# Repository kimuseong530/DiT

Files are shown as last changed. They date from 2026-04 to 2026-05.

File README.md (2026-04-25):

# DiT — Digital Twin Truck

> 손 제스처로 조종하는 소형 트럭 + Unity 디지털 트윈 실시간 동기화 시스템

---

## 프로젝트 개요
장갑에 내장된 IMU 센서로 손의 움직임을 인식하고,
Wi-Fi(MQTT) 통신을 통해 3D 프린팅 기반 소형 트럭을 제어합니다.
트럭의 실시간 위치·자세 데이터는 Unity 가상환경에 동기화되어
디지털 트윈으로 시각화됩니다.

---

## 시스템 구성

[ 장갑 (ESP32 + MPU-6050) ]
        ↓ MQTT (glove/left, glove/right)
[ Raspberry Pi — Mosquitto 브로커 ]
        ↓ MQTT (truck/cmd, truck/sensor)
[ 트럭 ESP32 — TB6612FNG — DC모터 ]
        ↓ MQTT (truck/sensor)
[ Unity 디지털 트윈 ]

---

## 제스처 동작 매핑

| 동작 | 기능 | 인식 방법 |
|---|---|---|
| 팔을 앞으로 밀기 | 전진 | Pitch + |
| 팔을 뒤로 당기기 | 후진 | Pitch − |
| 왼쪽으로 기울임 | 좌회전 | Roll − |
| 오른쪽으로 기울임 | 우회전 | Roll + |
| 양손 위로 | 정지 | Z축 기준 |

---

## MQTT 토픽 구조

| 토픽 | 발행자 | 구독자 | 내용 |
|---|---|---|---|
| `glove/left` | 왼손 ESP32 | 트럭, Unity | pitch/roll/yaw |
| `glove/right` | 오른손 ESP32 | 트럭, Unity | pitch/roll/yaw |
| `truck/cmd` | 트럭 ESP32 | Unity | 모터 명령값 |
| `truck/sensor` | 트럭 ESP32 | Unity | 인코더 피드백 |

---

## 하드웨어 구성
- ESP32 DevKitC WROOM-32D × 3
- MPU-6050 (GY-521) × 2
- TB6612FNG 모터드라이버 × 1
- 인코더 내장 DC모터 (6V 52RPM) × 2
- Raspberry Pi 4 Model B (MQTT 브로커)

---

## 실행 방법

### 1. Raspberry Pi — MQTT 브로커
```bash
cd raspberry_pi
bash setup.sh
```

### 2. ESP32 — 장갑 / 트럭
- `secrets.h`에 Wi-Fi SSID/PW 입력
- Arduino IDE에서 각 `.ino` 업로드

### 3. Unity
- `unity/` 폴더를 Unity Hub에서 열기
- MQTT 브로커 IP 설정 후 실행

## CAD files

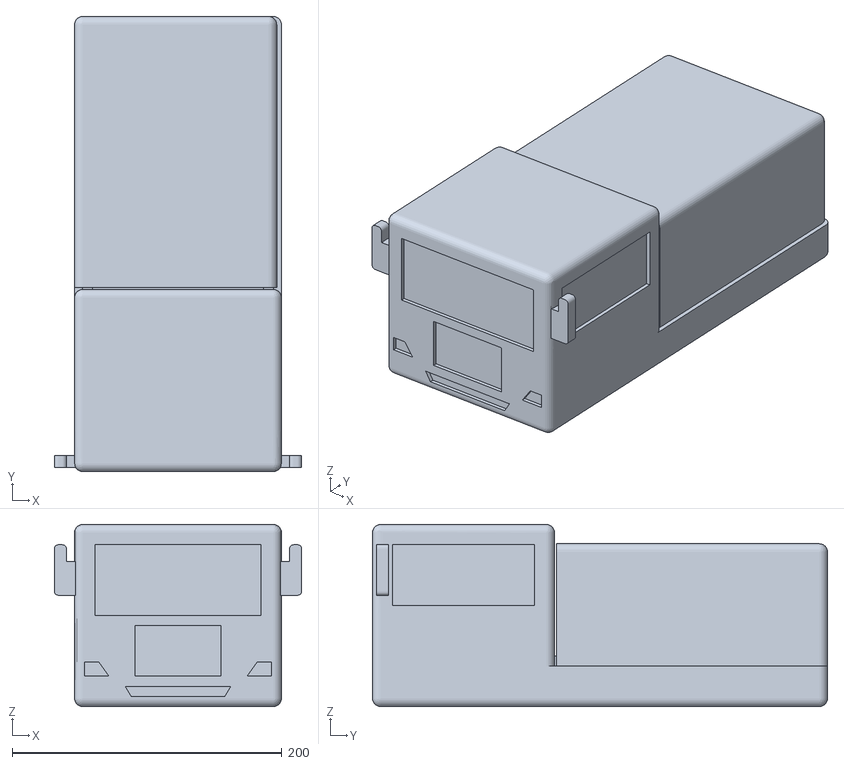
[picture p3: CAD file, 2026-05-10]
3d_model/Truck.stl
183.5 x 337.5 x 135.0

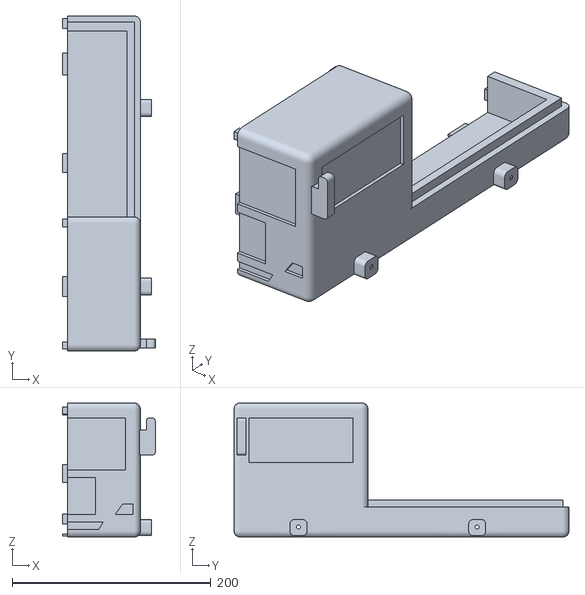
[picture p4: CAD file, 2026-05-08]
3d_model/truck_half(test).stl
93.2 x 337.5 x 135.0

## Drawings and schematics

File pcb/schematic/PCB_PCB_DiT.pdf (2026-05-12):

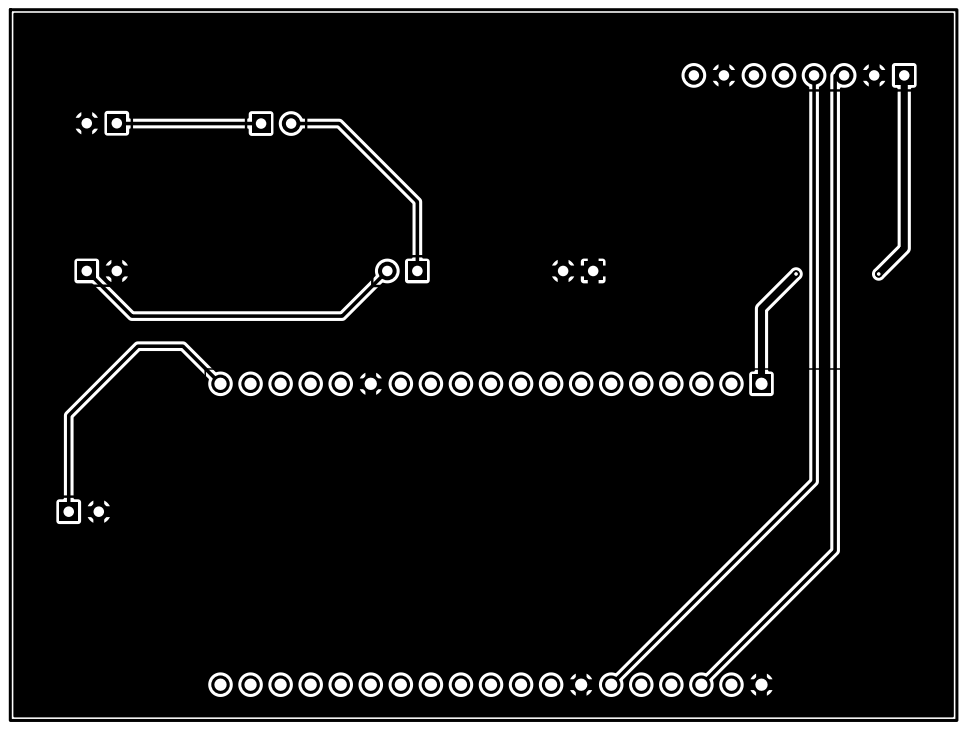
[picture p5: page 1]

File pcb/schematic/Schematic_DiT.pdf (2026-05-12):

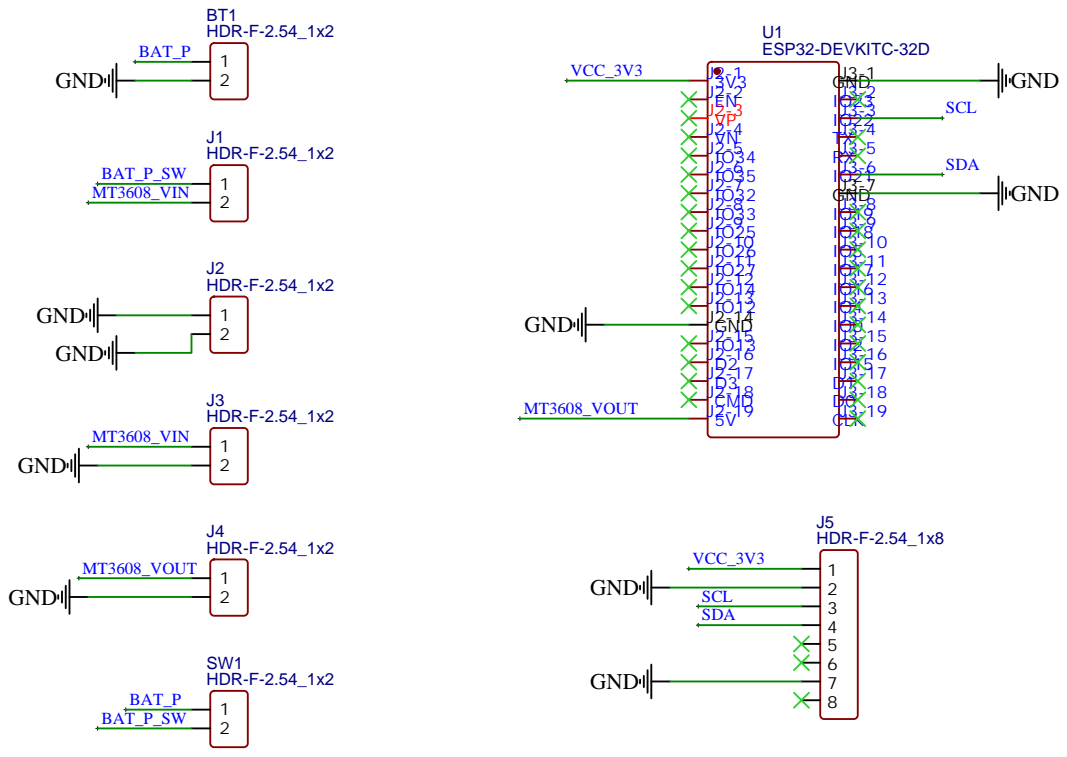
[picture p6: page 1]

Drawn By: Kim USeong

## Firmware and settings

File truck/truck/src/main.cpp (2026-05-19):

// #include <Arduino.h>
// #include <WiFi.h>
// #include <PubSubClient.h>
// #include <ArduinoJson.h>

// // ⚠️ Wi-Fi / MQTT 설정
// const char* WIFI_SSID     = "여기에_SSID";
// const char* WIFI_PASSWORD = "여기에_PW";
// const char* MQTT_BROKER   = "라즈베리파이_IP";
// const int   MQTT_PORT     = 1883;

// // ===== TB6612FNG 핀 정의 =====
// #define AIN1 25
// #define AIN2 26
// #define PWMA 27
// #define BIN1 14
// #define BIN2 23   // ✅ 12 → 23 변경 (부팅 문제 핀 회피)
// #define PWMB 13

// // ===== 인코더 핀 정의 =====
// #define ENC_L_A 18
// #define ENC_L_B 19
// #define ENC_R_A 34
// #define ENC_R_B 35

// // ===== LEDC PWM 설정 =====
// // ✅ ESP32는 analogWrite 없음 → ledcWrite 사용
// #define CH_L      0
// #define CH_R      1
// #define PWM_FREQ  5000
// #define PWM_BIT   8     // 0~255

// // ===== 인코더 스펙 =====
// #define PPR          11
// #define GEAR_RATIO   298
// #define WHEEL_RADIUS 0.033   // 66mm → 반지름 33mm
// #define WHEEL_BASE   0.15     // 바퀴 간격 (실측 후 수정!)

// // ===== 제스처 임계값 =====
// #define PITCH_FWD    15.0
// #define PITCH_BWD   -15.0
// #define ROLL_RIGHT   15.0
// #define ROLL_LEFT   -15.0
// #define STOP_AZ      0.3
// #define MOTOR_SPEED  150

// // ===== 인코더 변수 =====
// volatile long encL_count = 0;
// volatile long encR_count = 0;

// float distL_total = 0;
// float distR_total = 0;
// float heading     = 0;

// const float DIST_PER_PULSE = (2.0 * PI * WHEEL_RADIUS) / (PPR * GEAR_RATIO);

// // ===== 장갑 데이터 =====
// float left_pitch = 0, left_roll = 0, left_az = 1;
// float right_pitch = 0, right_roll = 0, right_az = 1;

// WiFiClient espClient;
// PubSubClient mqtt(espClient);

// unsigned long lastSensorPublish = 0;
// #define SENSOR_INTERVAL 100

// // ===== 인터럽트 핸들러 =====
// void IRAM_ATTR encL_ISR() {
//   if (digitalRead(ENC_L_B) == HIGH) encL_count++;
//   else encL_count--;
// }

// void IRAM_ATTR encR_ISR() {
//   if (digitalRead(ENC_R_B) == HIGH) encR_count++;
//   else encR_count--;
// }

// // ===== 모터 제어 함수 =====
// // ✅ analogWrite → ledcWrite 전체 교체
// void motorStop() {
//   digitalWrite(AIN1, LOW); digitalWrite(AIN2, LOW); ledcWrite(CH_L, 0);
//   digitalWrite(BIN1, LOW); digitalWrite(BIN2, LOW); ledcWrite(CH_R, 0);
//   Serial.println("🛑 정지");
// }

// void motorForward(int speed) {
//   digitalWrite(AIN1, HIGH); digitalWrite(AIN2, LOW); ledcWrite(CH_L, speed);
//   digitalWrite(BIN1, HIGH); digitalWrite(BIN2, LOW); ledcWrite(CH_R, speed);
//   Serial.println("⬆️ 전진");
// }

// void motorBackward(int speed) {
//   digitalWrite(AIN1, LOW); digitalWrite(AIN2, HIGH); ledcWrite(CH_L, speed);
//   digitalWrite(BIN1, LOW); digitalWrite(BIN2, HIGH); ledcWrite(CH_R, speed);
//   Serial.println("⬇️ 후진");
// }

// void motorLeft(int speed) {
//   digitalWrite(AIN1, LOW); digitalWrite(AIN2, HIGH); ledcWrite(CH_L, speed);
//   digitalWrite(BIN1, HIGH); digitalWrite(BIN2, LOW); ledcWrite(CH_R, speed);
//   Serial.println("⬅️ 좌회전");
// }

// void motorRight(int speed) {
//   digitalWrite(AIN1, HIGH); digitalWrite(AIN2, LOW); ledcWrite(CH_L, speed);
//   digitalWrite(BIN1, LOW); digitalWrite(BIN2, HIGH); ledcWrite(CH_R, speed);
//   Serial.println("➡️ 우회전");
// }

// // ===== 인코더 → 거리/방향 계산 =====
// void updateOdometry() {
//   long countL = encL_count; encL_count = 0;
//   long countR = encR_count; encR_count = 0;

//   float dL = countL * DIST_PER_PULSE;
//   float dR = countR * DIST_PER_PULSE;

//   distL_total += abs(dL);
//   distR_total += abs(dR);

//   float dTheta = (dR - dL) / WHEEL_BASE;
//   heading += dTheta * (180.0 / PI);

//   if (heading > 360) heading -= 360;
//   if (heading < 0)   heading += 360;
// }

// // ===== 센서 데이터 MQTT 발행 =====
// void publishSensorData() {
//   updateOdometry();

//   float avgDist = (distL_total + distR_total) / 2.0;

//   char payload[128];
//   snprintf(payload, sizeof(payload),
//     "{\"dist\":%.4f,\"distL\":%.4f,\"distR\":%.4f,\"heading\":%.2f}",
//     avgDist, distL_total, distR_total, heading);

//   mqtt.publish("truck/sensor", payload);
//   Serial.println(payload);
// }

// // ===== 제스처 판단 =====
// void applyGestureRule() {
//   if (left_az < STOP_AZ && right_az < STOP_AZ) {
//     motorStop(); return;
//   }
//   if      (left_pitch > PITCH_FWD)  motorForward(MOTOR_SPEED);
//   else if (left_pitch < PITCH_BWD)  motorBackward(MOTOR_SPEED);
//   else if (left_roll  < ROLL_LEFT)  motorLeft(MOTOR_SPEED);
//   else if (left_roll  > ROLL_RIGHT) motorRight(MOTOR_SPEED);
//   else                              motorStop();
// }

// // ===== MQTT 수신 콜백 =====
// void mqttCallback(char* topic, byte* payload, unsigned int length) {
//   payload[length] = '\0';

//   StaticJsonDocument<128> doc;
//   deserializeJson(doc, payload);

//   if (String(topic) == "glove/left") {
//     left_pitch = doc["pitch"];
//     left_roll  = doc["roll"];
//     left_az    = doc["az"];
//   } else if (String(topic) == "glove/right") {
//     right_pitch = doc["pitch"];
//     right_roll  = doc["roll"];
//     right_az    = doc["az"];
//   }

//   applyGestureRule();
// }

// // ===== Wi-Fi 연결 =====
// void connectWiFi() {
//   WiFi.begin(WIFI_SSID, WIFI_PASSWORD);
//   Serial.print("Wi-Fi 연결 중");
//   while (WiFi.status() != WL_CONNECTED) {
//     delay(500); Serial.print(".");
//   }
//   Serial.println("\n✅ Wi-Fi 연결 성공!");
//   Serial.print("IP: ");
//   Serial.println(WiFi.localIP());
// }

// // ===== MQTT 연결 =====
// void connectMQTT() {
//   while (!mqtt.connected()) {
//     Serial.print("MQTT 연결 중...");
//     if (mqtt.connect("truck")) {
//       mqtt.subscribe("glove/left");
//       mqtt.subscribe("glove/right");
//       Serial.println("✅ MQTT 연결 성공!");
//     } else {
//       Serial.print("실패, rc=");
//       Serial.println(mqtt.state());
//       delay(2000);
//     }
//   }
// }

// // ===== setup =====
// void setup() {
//   Serial.begin(115200);

//   // 모터 방향 핀 설정
//   pinMode(AIN1, OUTPUT); pinMode(AIN2, OUTPUT);
//   pinMode(BIN1, OUTPUT); pinMode(BIN2, OUTPUT);

//   // ✅ LEDC PWM 채널 설정
//   ledcSetup(CH_L, PWM_FREQ, PWM_BIT);
//   ledcSetup(CH_R, PWM_FREQ, PWM_BIT);
//   ledcAttachPin(PWMA, CH_L);
//   ledcAttachPin(PWMB, CH_R);

//   motorStop();

//   // 인코더 핀 설정
//   pinMode(ENC_L_A, INPUT_PULLUP);
//   pinMode(ENC_L_B, INPUT_PULLUP);
//   pinMode(ENC_R_A, INPUT_PULLUP);  // GPIO34는 내부 풀업 없음
//   pinMode(ENC_R_B, INPUT_PULLUP);  // GPIO35는 내부 풀업 없음

//   // 인터럽트 등록
//   attachInterrupt(digitalPinToInterrupt(ENC_L_A), encL_ISR, RISING);
//   attachInterrupt(digitalPinToInterrupt(ENC_R_A), encR_ISR, RISING);

//   connectWiFi();
//   mqtt.setServer(MQTT_BROKER, MQTT_PORT);
//   mqtt.setCallback(mqttCallback);
//   connectMQTT();
// }

// // ===== loop =====
// void loop() {
//   if (!mqtt.connected()) connectMQTT();
//   mqtt.loop();

//   if (millis() - lastSensorPublish >= SENSOR_INTERVAL) {
//     publishSensorData();
//     lastSensorPublish = millis();
//   }
// }


#include <Arduino.h>

#define BIN1_FR  5
#define BIN2_FR  17
#define PWMB_FR  16
#define ENC_A_FR 21
#define ENC_B_FR 22

#define CH_FR    0
#define PWM_FREQ 5000
#define PWM_BIT  8

volatile long encoderCount = 0;

void IRAM_ATTR encoderISR() {
  if (digitalRead(ENC_B_FR) == HIGH) encoderCount++;
  else encoderCount--;
}

void setup() {
  Serial.begin(115200);

  pinMode(BIN1_FR, OUTPUT);
  pinMode(BIN2_FR, OUTPUT);
  pinMode(ENC_A_FR, INPUT);
  pinMode(ENC_B_FR, INPUT);

  attachInterrupt(digitalPinToInterrupt(ENC_A_FR), encoderISR, RISING);

  ledcSetup(CH_FR, PWM_FREQ, PWM_BIT);
  ledcAttachPin(PWMB_FR, CH_FR);

  Serial.println("=== 앞R 모터 테스트 ===");
  delay(1000);

  // 전진
  Serial.println("[1] 전진 2초");
  encoderCount = 0;
  digitalWrite(BIN1_FR, HIGH);
  digitalWrite(BIN2_FR, LOW);
  ledcWrite(CH_FR, 150);
  delay(2000);
  ledcWrite(CH_FR, 0);
  Serial.print("인코더 카운트: ");
  Serial.println(encoderCount);
  delay(1000);

  // 후진
  Serial.println("[2] 후진 2초");
  encoderCount = 0;
  digitalWrite(BIN1_FR, LOW);
  digitalWrite(BIN2_FR, HIGH);
  ledcWrite(CH_FR, 150);
  delay(2000);
  ledcWrite(CH_FR, 0);
  Serial.print("인코더 카운트: ");
  Serial.println(encoderCount);

  Serial.println("=== 테스트 완료 ===");
}

void loop() {
  Serial.print("인코더: ");
  Serial.println(encoderCount);
  delay(300);
}

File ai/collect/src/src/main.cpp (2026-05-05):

#include <Arduino.h>
#include <Wire.h>
#include <MPU6050.h>

MPU6050 mpu;

// 제스처 라벨
// 0: 전진, 1: 후진, 2: 좌회전, 3: 우회전, 4: 정지
int currentLabel = 0;

// 한 샘플당 시계열 길이
#define SAMPLE_SIZE 20
#define SAMPLE_DELAY 50  // ms

void setup() {
  Serial.begin(115200);
  Wire.begin();

  mpu.initialize();
  if (!mpu.testConnection()) {
    Serial.println("❌ MPU6050 연결 실패!");
    while (1);
  }

  Serial.println("✅ 준비 완료!");
  Serial.println("라벨 입력 → 0:전진 1:후진 2:좌회전 3:우회전 4:정지");
  Serial.println("원하는 숫자 입력 후 엔터 → 수집 시작");
}

void collectSample() {
  Serial.println("3초 후 수집 시작...");
  delay(3000);

  for (int i = 0; i < SAMPLE_SIZE; i++) {
    int16_t ax, ay, az, gx, gy, gz;
    mpu.getMotion6(&ax, &ay, &az, &gx, &gy, &gz);

    float accel_x = ax / 16384.0;
    float accel_y = ay / 16384.0;
    float accel_z = az / 16384.0;
    float gyro_x  = gx / 131.0;
    float gyro_y  = gy / 131.0;
    float gyro_z  = gz / 131.0;

    float pitch = atan2(accel_y, accel_z) * 180.0 / PI;
    float roll  = atan2(-accel_x, accel_z) * 180.0 / PI;

    // CSV 형식으로 출력 → PC에서 저장
    Serial.print(pitch); Serial.print(",");
    Serial.print(roll);  Serial.print(",");
    Serial.print(accel_x); Serial.print(",");
    Serial.print(accel_y); Serial.print(",");
    Serial.print(accel_z); Serial.print(",");
    Serial.print(gyro_x); Serial.print(",");
    Serial.print(gyro_y); Serial.print(",");
    Serial.print(gyro_z); Serial.print(",");
    Serial.println(currentLabel);

    delay(SAMPLE_DELAY);
  }
  Serial.println("✅ 샘플 수집 완료!");
}

void loop() {
  if (Serial.available()) {
    char input = Serial.read();
    if (input >= '0' && input <= '4') {
      currentLabel = input - '0';
      String labels[] = {"전진","후진","좌회전","우회전","정지"};
      Serial.print("라벨: "); Serial.println(labels[currentLabel]);
      collectSample();
    }
  }
}

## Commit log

2026-04-22 프로젝트 초기 폴더 구조 생성
2026-04-25 left_glove MPU6050 테스트 코드 추가
2026-04-26 right_glove MPU6050 테스트 코드 추가
2026-04-29 모터 테스트
2026-05-01 left_glove MQTT 코드 추가
2026-05-01 right_glove 규칙 기반 제스처 코드 추가, DS_Store 제거
2026-05-02 truck 인코더 및 주행 거리 계산 코드 추가
2026-05-03 라즈베리파이 MQTT 브로커 설정 추가
2026-05-05 AI 제스처 학습 데이터 수집 및 학습 코드 추가
2026-05-06 pcb1차 개발
2026-05-08 트럭 3D 모델 STL 파일 추가
    [truck_half(test).stl]
2026-05-12 EasyEDA 스케매틱 및 보드 이미지 추가
    [Truck.stl, truck_half(test).stl]
2026-05-12 전체 파일 복구
    [Truck.stl, truck_half(test).stl]
2026-05-13 truck코드 수정
2026-05-19 오른쪽 앞 모터 테스트
2026-05-20 트럭 기본 움직임 구현
